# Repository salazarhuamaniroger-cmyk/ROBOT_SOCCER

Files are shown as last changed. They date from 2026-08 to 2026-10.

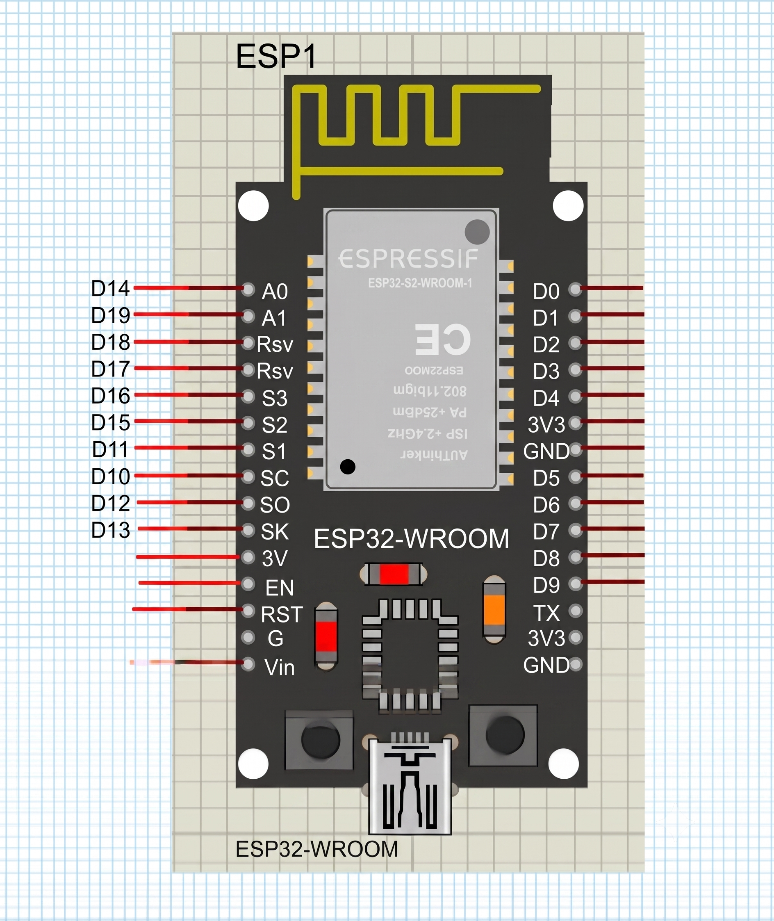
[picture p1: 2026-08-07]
imagenes/equivalencia_de_pines.png

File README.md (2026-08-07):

# 🐂 PITBULL V2.0.0

Sistema de control y desarrollo de un robot SoccerBot basado en **ESP32**, con control mediante interfaz web, comunicación Wi-Fi, simulación electrónica en **Proteus**, programación mediante **Arduino IDE** y modelo 3D para fabricación del chasis.

---

# 📑 Índice

- [Descripción del proyecto](#-descripción-del-proyecto)
- [Estructura del repositorio](#-estructura-del-repositorio)
- [Estructura del proyecto](#-estructura-del-proyecto-1)
  - [Electrónica](#-electrónica)
  - [Código](#-código)
  - [Modelo 3D](#-modelo-3d)
- [Simulación en Proteus](#-simulación-en-proteus)
  - [Esquema electrónico](#-esquema-electrónico)
  - [Instalación de la librería ESP32 en Proteus](#-instalación-de-la-librería-esp32-en-proteus)
  - [Consideraciones sobre la simulación](#-consideraciones-sobre-la-simulación)
  - [Equivalencia de pines](#-equivalencia-de-pines)
  - [Obtención del archivo HEX](#-obtención-del-archivo-hex)
  - [Carga del binario en Proteus](#-carga-del-binario-en-proteus)
- [Código del SoccerBot](#-código-del-soccerbot)
- [Documentación del código](#-documentación-del-código)
  - [Librerías](#1-librerías)
  - [Configuración de red](#2-configuración-de-red)
  - [Asignación de pines](#3-asignación-de-pines)
  - [Watchdog de seguridad](#4-watchdog-de-seguridad)
  - [Interfaz web](#5-interfaz-web)
  - [Control de motores](#6-control-de-motores)
  - [Cinemática Arcade Drive](#7-cinemática-arcade-drive)
  - [Servidor HTTP](#8-servidor-http)
  - [Sistema de secuencia](#9-sistema-de-secuencia)
  - [OTA](#10-actualización-ota)
  - [Loop principal](#11-loop-principal)
- [Flujo general del sistema](#-flujo-general-del-sistema)
- [Modelo 3D](#-modelo-3d-1)
- [Funcionamiento general](#-funcionamiento-general)
- [Consideraciones importantes](#-consideraciones-importantes)
- [Referencias](#-referencias)

---

#  Descripción del proyecto

**PITBULL V2.0.0** es un proyecto de robótica móvil orientado al desarrollo de un **robot SoccerBot**.

El proyecto integra tres áreas principales:

1. **Electrónica**
2. **Programación y control**
3. **Diseño mecánico y fabricación 3D**

El sistema utiliza un **ESP32** como unidad principal de control. El robot puede recibir comandos mediante una interfaz web alojada directamente en el ESP32 utilizando una red Wi-Fi creada por el propio dispositivo.

El proyecto también cuenta con una simulación electrónica desarrollada en **Proteus**, que permite comprobar previamente el funcionamiento lógico del sistema antes de llevarlo al hardware físico.

---

# 📁 Estructura del repositorio

La estructura general del repositorio es la siguiente:

```text
PITBULL-V2.0.0/
│
├── README.md
│       └── Documentación principal del repositorio
│
├── codigo/
│       └── Firmware en C/C++ para Arduino IDE
│
├── electronica/
│       ├── SOCCER 3.0.pdsprj
│       │       └── Esquemático y simulación de Proteus
│       │
│       └── libreria_proteus/
│               ├── ESP32TEP.LIB
│               └── ESP32TEP.IDX
│
├── imagenes/
│       └── Capturas, diagramas de flujo e instrucciones visuales
│
└── modelo_3d/
        └── Archivos CAD (.STL, .STEP) para el chasis```

🏗️**structura del proyecto**

Avanzaremos inicialmente por las partes principales del proyecto.

⚡ Electrónica

El esquema electrónico general del proyecto se encuentra representado en Proteus.

Diagrama general

![DIAGRAMA EN PROTEUS](imagenes/diagrama_general_soccer.png)

El esquema muestra la conexión general de los componentes electrónicos utilizados en el SoccerBot.

📂 Archivos de la simulación

Los archivos principales de la simulación se encuentran en:
/home/tronyx/PITBULL-V2.0.0/electronica/

Dentro de esta carpeta se encuentran principalmente:

1. SOCCER 3.0.pdsprj

Este archivo contiene el proyecto y el esquemático desarrollado en Proteus.

Es el archivo que debe abrirse para acceder a la simulación electrónica.

2. codigo_simulacion_proteus.ino

Este archivo contiene el código utilizado para la simulación.

Puede abrirse mediante Arduino IDE para realizar modificaciones, compilarlo y posteriormente generar el archivo binario necesario para Proteus.

🧩 Librería ESP32 para Proteus

Los componentes utilizados en el esquemático se encuentran principalmente dentro del archivo:

SOCCER 3.0.pdsprj

La excepción corresponde al componente ESP32, debido a que se utiliza una librería externa.

La librería del ESP32 se encuentra dentro del repositorio en:

/home/tronyx/PITBULL-V2.0.0/electronica/libreria_proteus/

Esta carpeta contiene dos archivos:

ESP32TEP.LIB
ESP32TEP.IDX

Estos archivos deben instalarse manualmente en la carpeta correspondiente de Proteus.

🔧 Instalación de la librería ESP32 en Proteus

Para añadir la librería ESP32 a Proteus:

1. Localizar los archivos

Dentro del repositorio se encuentran los siguientes archivos:

/home/tronyx/PITBULL-V2.0.0/electronica/libreria_proteus/

Allí se encuentran:

ESP32TEP.LIB
ESP32TEP.IDX

2. Localizar la carpeta de librerías de Proteus

Busca en tu instalación de Proteus la carpeta donde se encuentran sus librerías.

La ubicación exacta puede variar dependiendo de la versión e instalación de Proteus.

Para localizarla puedes utilizar como referencia la siguiente imagen:

![Librerías de Proteus](/home/tronyx/PITBULL-V2.0.0/imagenes/'añadir libreria_proteus.png')

3. Copiar los archivos

Copia los dos archivos:

ESP32TEP.LIB
ESP32TEP.IDX

dentro de la carpeta:

Libraries

de Proteus.

4. Reiniciar Proteus

Después de copiar los archivos:

Cierra Proteus.
Vuelve a abrir Proteus.
Abre nuevamente el proyecto.
Busca el componente ESP32.

Si todo se realizó correctamente, el componente debería estar disponible.

⚠️ Si el componente ESP32 no aparece

Si el componente no aparece después de instalar la librería:

Verifica que los archivos .LIB y .IDX estén en la carpeta correcta.
Comprueba que Proteus haya sido cerrado antes de copiar los archivos.
Reinicia Proteus.
Comprueba que el archivo del proyecto siga utilizando el componente correcto.

Si el archivo de Proteus fue trasladado de ubicación, revisa también las rutas asociadas al proyecto.

📚 Referencia para instalar librerías

Para obtener información adicional sobre la instalación y configuración de librerías en Proteus:

https://www.theengineeringprojects.com/2018/04/how-to-add-new-library-in-proteus-8.html
⚠️ Consideraciones sobre la simulación

Aunque el componente utilizado en Proteus pueda representar físicamente un ESP32, la simulación utiliza una representación equivalente para permitir el funcionamiento del modelo dentro de Proteus.

Por este motivo, es importante diferenciar entre:

La placa utilizada físicamente.
El componente utilizado en Proteus.
La configuración seleccionada en Arduino IDE para generar el código.

La simulación tiene como objetivo comprobar principalmente:

La lógica del programa.
Las señales de control.
La dirección de los motores.
El comportamiento de las entradas y salidas.
La comunicación entre los diferentes elementos del circuito.

El hardware físico deberá utilizar la versión real de ESP32 correspondiente al diseño final.

🔌 Equivalencia de pines

Debido a que el modelo de ESP32 utilizado en Proteus puede presentar una distribución de pines diferente respecto a la placa física, se debe utilizar una tabla de equivalencias.

![Equivalencia de pines](/home/tronyx/PITBULL-V2.0.0/imagenes/'equivalencia de pines.png')

Esta equivalencia permite adaptar el circuito simulado al hardware real.

Importante: la equivalencia debe comprobarse antes de realizar el montaje físico.

💻 Obtención del archivo HEX

Para ejecutar el firmware dentro de Proteus es necesario proporcionar el archivo binario generado por Arduino IDE.

El procedimiento es el siguiente.

1. Compilar el programa

Abre el código mediante Arduino IDE.

Una vez que el código haya sido verificado y compilado correctamente, abre:

Programa

y posteriormente:

Binarios compilados

2. Localizar el archivo generado

Arduino IDE generará diferentes archivos temporales.

Uno de ellos tendrá una ruta similar a:

**C:\Users\Lenovo\AppData\Local\Temp\arduino_build_438877\codigo_de_prueba_v0003.ino.hex**

El nombre:

codigo_de_prueba_v0003

es solamente un ejemplo.

El nombre real dependerá del nombre que tenga el archivo .ino utilizado en Arduino IDE.

🧪 Carga del binario en Proteus

Una vez obtenido el archivo .hex:

1. Abrir Proteus

Abre:

SOCCER 3.0.pdsprj
2. Seleccionar el ESP32

Haz doble clic sobre el componente ESP32 dentro del esquemático.

Se abrirá la ventana de propiedades del componente.

3. Introducir el archivo HEX

Busca el campo correspondiente al archivo de programa y selecciona el archivo .hex generado por Arduino IDE.

Después pulsa:

OK

La simulación podrá comenzar.

🔄 Si vuelves a modificar el código

El archivo binario es temporal.

Por lo tanto, cada vez que modifiques el código:

Abre el código en Arduino IDE.
Compílalo nuevamente.
Genera el nuevo binario.
Localiza el nuevo archivo .hex.
Vuelve a introducirlo en Proteus.
Ejecuta nuevamente la simulación.

📚 Referencia adicional
Si tienes dificultades para generar o utilizar el binario del ESP32 en Proteus:

https://www.theengineeringprojects.com/2023/07/esp32-library-for-proteus.html

💻 Código del SoccerBot

Una vez validado el flujo lógico, la electrónica y la simulación, se puede trabajar directamente con el firmware y el hardware real del SoccerBot.

El código principal se encuentra en:

/home/tronyx/PITBULL-V2.0.0/codigo/

El firmware debe abrirse mediante Arduino IDE.

🧠 Configuración del robot

El código contiene una constante que define el nombre mostrado en la interfaz:

const char* NOMBRE_ROBOT = "PITBULL V.200";

En la interfaz web este nombre se muestra como:

PITBULL V.200

El nombre puede modificarse directamente desde el código.

📡 Sistema de comunicación

El SoccerBot utiliza el ESP32 como punto de acceso Wi-Fi (Access Point).

Esto significa que el ESP32 crea su propia red inalámbrica.

La configuración utilizada es:

const char* ap_ssid = "SoccerBot-AP";
const char* ap_password = "PITBULL_rt79";

Por lo tanto, el dispositivo que controla el robot debe conectarse a:

SSID:
SoccerBot-AP

con la contraseña:

PITBULL_rt79

La dirección IP habitual del ESP32 en este modo es:

192.168.4.1

Por lo tanto, la interfaz puede abrirse normalmente mediante:

http://192.168.4.1
🌐 Documentación del código

Esta sección explica el funcionamiento interno del firmware.

1. Librerías

El código comienza incluyendo:

#include <WiFi.h>
#include <ArduinoOTA.h>
#include <WebServer.h>
#include <ESPmDNS.h>

Cada librería cumple una función específica.

WiFi.h

Permite configurar y controlar la conexión Wi-Fi del ESP32.

En este proyecto se utiliza para crear el Access Point.

ArduinoOTA.h

Permite realizar actualizaciones del firmware mediante OTA (Over-The-Air).

Esto permite actualizar el programa sin necesidad de conectar físicamente el ESP32 para cada modificación.

WebServer.h

Proporciona el servidor HTTP utilizado para recibir las órdenes provenientes de la interfaz web.

El servidor funciona en el puerto:

80
ESPmDNS.h

Permite utilizar nombres de red mediante mDNS.

El código intenta registrar:

soccerbot.local

como alternativa a utilizar directamente la dirección IP.

2. Configuración de red

El código utiliza:

WiFi.mode(WIFI_AP);

Esto configura al ESP32 como Access Point.

Posteriormente:

WiFi.softAP(ap_ssid, ap_password);

crea la red:

SoccerBot-AP

El ESP32 funciona entonces como el punto central de comunicación.

El flujo es:

Teléfono / Laptop
       │
       │ Wi-Fi
       ▼
   ESP32
       │
       ├── Servidor HTTP
       │
       └── Control de motores

3. Asignación de pines

El código define los pines utilizados por el controlador de motores TB6612FNG.

const int PWMA_PIN = 14;
const int AIN1_PIN = 18;
const int AIN2_PIN = 21;

const int PWMB_PIN = 35;
const int BIN1_PIN = 16;
const int BIN2_PIN = 17;

La estructura lógica es:

Función	Pin
PWMA	GPIO 14
AIN1	GPIO 18
AIN2	GPIO 21
PWMB	GPIO 35
BIN1	GPIO 16
BIN2	GPIO 17

El TB6612FNG utiliza dos canales independientes:

Canal A → Motor izquierdo
Canal B → Motor derecho

4. Watchdog de seguridad

El robot incorpora un mecanismo de seguridad basado en tiempo.

unsigned long lastCommandTime = 0;

const unsigned long COMMAND_TIMEOUT_MS = 300;

El tiempo máximo permitido sin recibir una orden es:

300 ms

Si el ESP32 deja de recibir comandos durante más de ese tiempo, ejecuta:

detenerTodo();

Esto provoca que ambos motores se detengan.

¿Por qué existe el watchdog?

Supongamos que el teléfono pierde la conexión mientras el robot está avanzando.

Sin un mecanismo de seguridad:

Teléfono → "avanzar"
ESP32 → motores funcionando
Teléfono → conexión perdida
ESP32 → podría continuar funcionando

Con el watchdog:

Teléfono → "avanzar"
ESP32 → motores funcionando

Conexión perdida
       ↓
No llegan comandos
       ↓
300 ms
       ↓
detenerTodo()
       ↓
Motores detenidos

Este mecanismo evita que una pérdida de comunicación deje al robot desplazándose indefinidamente.

5. Interfaz web

La interfaz completa está almacenada dentro del firmware mediante:

const char INDEX_HTML[] PROGMEM = R"rawliteral(
...
)rawliteral";

Esto permite almacenar el HTML directamente dentro de la memoria del programa del ESP32.

La interfaz está formada por:

Control mediante botones.
Control mediante joystick lineal.
Limitador de PWM.
Telemetría.
Indicador de red.
Indicador de potencia.
Indicador de giro.
Selector de modo.
Nombre del robot.

🎮 **Modos de control**

La interfaz tiene dos modos principales.

Modo 1: BOTONES

Permite controlar el robot mediante cuatro botones:

        ▲
        │
   ◀         ▶
        │
        ▼

El eje X controla el giro:

X < 0 → izquierda
X > 0 → derecha

El eje Y controla el desplazamiento:

Y > 0 → adelante
Y < 0 → atrás
Modo 2: DUAL PRO

Utiliza dos controles lineales:

Joystick X → Giro
Joystick Y → Potencia

El eje X produce valores entre:

-255 ───── 0 ───── +255

El eje Y también trabaja con valores entre:

-255 ───── 0 ───── +255

6. Control de motores

La función principal encargada del control de los motores es:

void operarMotor(bool esIzquierdo, int velocidad)

Recibe dos parámetros:

esIzquierdo

Indica qué motor se debe controlar.

true

significa motor izquierdo.

false

significa motor derecho.

velocidad

Representa la velocidad y dirección:

-255 → máxima velocidad en una dirección
   0 → detenido
+255 → máxima velocidad en la dirección opuesta

La función determina automáticamente los pines correspondientes:

int in1 = esIzquierdo ? AIN1_PIN : BIN1_PIN;
int in2 = esIzquierdo ? AIN2_PIN : BIN2_PIN;
int pwmPin = esIzquierdo ? PWMA_PIN : PWMB_PIN;
Motor hacia adelante

Cuando:

velocidad > 0

se establece:

digitalWrite(in1, LOW);
digitalWrite(in2, HIGH);

y posteriormente se aplica el PWM:

ledcWrite(pwmPin, velocidad);
Motor hacia atrás

Cuando:

velocidad < 0

se establece:

digitalWrite(in1, HIGH);
digitalWrite(in2, LOW);

La velocidad utilizada por PWM se obtiene mediante:

abs(velocidad)
Motor detenido

Cuando:

velocidad == 0

se establece:

digitalWrite(in1, LOW);
digitalWrite(in2, LOW);
ledcWrite(pwmPin, 0);

7. Cinemática Arcade Drive

El control de movimiento utiliza una estrategia conocida como Arcade Drive aplicada a una plataforma de tracción diferencial.

El navegador envía dos valores:

X = giro
Y = potencia

El ESP32 calcula:

int velIzq = y + x;
int velDer = y - x;

Por lo tanto:

Motor izquierdo = Y + X
Motor derecho    = Y - X
Movimiento hacia adelante

Si:

X = 0
Y = 200

entonces:

Motor izquierdo = 200
Motor derecho   = 200

Ambos motores avanzan a la misma velocidad.

Giro hacia la derecha

Si:

X = 100
Y = 0

entonces:

Motor izquierdo = 100
Motor derecho   = -100

Un motor avanza y el otro retrocede.

Esto produce un giro sobre el propio eje.

Movimiento combinado

Si:

X = 50
Y = 200

entonces:

Motor izquierdo = 250
Motor derecho   = 150

El robot avanza mientras gira.

Limitación de velocidad

Después de calcular las velocidades se aplica:

velIzq = constrain(velIzq, -255, 255);
velDer = constrain(velDer, -255, 255);

Esto garantiza que ningún valor supere el rango permitido:

-255 ≤ velocidad ≤ 255

8. Servidor HTTP

El ESP32 crea:

WebServer server(80);

Esto significa que el servidor HTTP utiliza el puerto:

80
Ruta principal /

La ruta:

/

devuelve la interfaz web.

El código correspondiente es:

server.on("/", []() {
    server.send(200, "text/html", INDEX_HTML);
});

Cuando el usuario accede a:

http://192.168.4.1/

el ESP32 devuelve el HTML almacenado en:

INDEX_HTML

9. Ruta /move

La ruta más importante del sistema es:

/move

Esta ruta recibe los valores:

x
y
seq

Un ejemplo sería:

/move?x=100&y=200&seq=25

El ESP32 obtiene:

int x = server.arg("x").toInt();
int y = server.arg("y").toInt();

y posteriormente calcula las velocidades de los motores.

Formato de la comunicación

El navegador genera una solicitud HTTP:

Teléfono
   │
   │ GET /move?x=100&y=200&seq=25
   ▼
 ESP32
   │
   ├── x = 100
   ├── y = 200
   └── seq = 25
        │
        ▼
 Cinemática
        │
        ▼
 TB6612FNG
        │
        ▼
 Motores
10. Sistema de secuencia

El código utiliza:

uint32_t lastSeq = 0;

La interfaz web mantiene un contador:

let seqCounter = 0;

Cada comando genera un número de secuencia nuevo:

const seq = ++seqCounter;

Esto permite identificar comandos antiguos.

El ESP32 compara:

if (seq < lastSeq)

Si el paquete recibido tiene una secuencia inferior a la última procesada, se considera antiguo:

server.send(200, "text/plain", "STALE");

De esta manera se evita procesar determinados comandos que hayan llegado fuera de orden.

11. Heartbeat del joystick

El modo DUAL PRO incorpora un mecanismo denominado heartbeat.

Cuando el usuario mantiene el joystick en una posición, la interfaz envía periódicamente el comando actual.

El intervalo utilizado es:

100 ms

Esto es importante debido al watchdog del ESP32.

El watchdog requiere recibir comandos dentro de:

300 ms

El heartbeat envía comandos cada:

100 ms

por lo que el ESP32 continúa considerando válida la orden mientras el usuario mantiene el joystick.

12. Limitador de PWM

La interfaz incorpora un control denominado:

LÍMITE PWM

El rango utilizado es:

50 → 255

El valor inicial es:

255

El objetivo es limitar la velocidad máxima solicitada desde la interfaz.

El valor se almacena en:

let maxLimit = 255;
13. Failsafe del navegador

La interfaz también implementa una protección adicional.

Se utiliza:

document.addEventListener('visibilitychange', ...)

Cuando la página pasa a segundo plano:

if (document.hidden)

se ejecuta:

stopAccX();
stopAccY();

Esto permite detener el control cuando, por ejemplo:

Se cambia de aplicación.
Se bloquea la pantalla.
Se abandona la página.

El objetivo es evitar que el robot continúe recibiendo comandos desde una interfaz que ya no está siendo controlada activamente.

14. Actualización OTA

El código incluye:

#include <ArduinoOTA.h>

y durante el inicio ejecuta:

ArduinoOTA.begin();

Posteriormente, en el loop():

ArduinoOTA.handle();

Esto permite gestionar las actualizaciones OTA.

El objetivo es poder actualizar el firmware utilizando la conexión de red disponible, evitando tener que conectar físicamente el programador cada vez que se realice una modificación del programa.

15. mDNS

El código intenta registrar el nombre:

soccerbot.local

mediante:

MDNS.begin("soccerbot")

Si el registro funciona correctamente, se puede intentar acceder mediante:

http://soccerbot.local

Sin embargo, dependiendo del dispositivo utilizado para controlar el robot, la resolución mDNS puede no funcionar correctamente.

Por esta razón, la dirección IP directa:

http://192.168.4.1

continúa siendo la referencia principal.

🔄 Flujo general del sistema

El funcionamiento completo puede representarse de la siguiente manera:

                  ┌─────────────────────┐
                  │       USUARIO       │
                  │ Teléfono / Laptop   │
                  └──────────┬──────────┘
                             │
                             │ Wi-Fi
                             ▼
                  ┌─────────────────────┐
                  │        ESP32        │
                  │   Access Point      │
                  │   192.168.4.1       │
                  └──────────┬──────────┘
                             │
                  ┌──────────┴──────────┐
                  │                     │
                  ▼                     ▼
          ┌───────────────┐     ┌───────────────┐
          │ Servidor HTTP │     │    Watchdog   │
          │     /move     │     │    300 ms     │
          └───────┬───────┘     └───────────────┘
                  │
                  ▼
          ┌───────────────┐
          │    Vector     │
          │    X / Y      │
          └───────┬───────┘
                  │
                  ▼
          ┌───────────────┐
          │ Arcade Drive  │
          │               │
          │ Izq = Y + X   │
          │ Der = Y - X   │
          └───────┬───────┘
                  │
                  ▼
          ┌───────────────┐
          │   TB6612FNG   │
          └───────┬───────┘
                  │
             ┌────┴────┐
             ▼         ▼
        Motor Izq.  Motor Der.

🧱 Modelo 3D

El modelo mecánico del robot se encuentra en:

/home/tronyx/PITBULL-V2.0.0/modelo_3d/

Dentro de esta carpeta se almacenan los archivos relacionados con el diseño CAD del robot.

Los formatos principales son:

.STL
.STEP
Formato STL

El formato .STL puede utilizarse principalmente para:

Impresión 3D.
Preparación del modelo en un slicer.
Fabricación de piezas.
Formato STEP

El formato .STEP permite trabajar con el modelo CAD de forma más editable y facilita modificaciones posteriores del diseño.

🖨️ Fabricación 3D

El modelo puede utilizarse para generar las piezas necesarias para fabricar el chasis del SoccerBot.

El flujo general es:

Modelo CAD
    │
    ▼
Archivo STEP / STL
    │
    ▼
Slicer
    │
    ▼
Impresora 3D
    │
    ▼
Pieza física

El modelo también puede modificarse para cambiar las características mecánicas del robot.

🧪 Funcionamiento general

El flujo completo del proyecto es:

                 DESARROLLO
                     │
        ┌────────────┼────────────┐
        │            │            │
        ▼            ▼            ▼
   Electrónica     Código      Modelo 3D
        │            │            │
        ▼            ▼            ▼
    Proteus      Arduino IDE    Fusion
        │            │            │
        ▼            ▼            ▼
   Simulación     Firmware      Chasis
        │            │            │
        └────────────┼────────────┘
                     ▼
                HARDWARE REAL
                     │
                     ▼
                  ESP32
                     │
                     ▼
                 TB6612FNG
                     │
             ┌───────┴───────┐
             ▼               ▼
        Motor izquierdo   Motor derecho

⚠️ C**onsideraciones importantes**

1. Simulación ≠ hardware físico

La simulación de Proteus es una representación del sistema.

Antes de montar el hardware real se deben verificar:

Alimentación.
Distribución de pines.
Corriente de los motores.
Conexiones del TB6612FNG.
GND común.
Alimentación del ESP32.
Polaridad de los motores.

2. Dirección de los motores

La dirección física de un motor depende de cómo estén conectados sus terminales.

Por ello, si el robot se mueve en dirección contraria a la esperada, primero debe comprobarse:

Motor
  │
  ├── Terminal A
  └── Terminal B

y posteriormente la lógica:

AIN1
AIN2

o:

BIN1
BIN2

3. Valores PWM

El sistema utiliza un rango:

-255 → 255

donde:

0   = detenido
255 = máxima potencia en un sentido
-255 = máxima potencia en el sentido contrario

4. Watchdog

El watchdog está configurado en:

const unsigned long COMMAND_TIMEOUT_MS = 300;

Esto significa que la comunicación con el robot debe mantenerse continuamente durante el movimiento.

5. Nombre del archivo HEX

El archivo .hex generado por Arduino IDE puede cambiar de nombre dependiendo del nombre del proyecto y de la compilación.

Por ejemplo:

codigo_de_prueba_v0003.ino.hex

no debe interpretarse como un nombre fijo.

6. Archivo binario para Proteus

Cada modificación del firmware requiere generar nuevamente el archivo binario antes de ejecutar la simulación con la nueva versión.

7. GPIO utilizado para PWMB

El firmware actual define:

const int PWMB_PIN = 35;

Este pin debe verificarse específicamente contra la placa ESP32 utilizada físicamente, ya que la disponibilidad de funciones de salida/PWM depende del modelo concreto de ESP32.

No se debe asumir que todos los GPIO tienen las mismas capacidades en todas las variantes de ESP32.

📂 **Rutas principales del proyecto**
Código
/home/tronyx/PITBULL-V2.0.0/codigo/
Electrónica
/home/tronyx/PITBULL-V2.0.0/electronica/
Librería Proteus
/home/tronyx/PITBULL-V2.0.0/electronica/libreria_proteus/
Imágenes
/home/tronyx/PITBULL-V2.0.0/imagenes/
Modelo 3D
/home/tronyx/PITBULL-V2.0.0/modelo_3d/
🔗 Referencias
Instalación de librerías en Proteus
https://www.theengineeringprojects.com/2018/04/how-to-add-new-library-in-proteus-8.html
Librería ESP32 para Proteus
https://www.theengineeringprojects.com/2023/07/esp32-library-for-proteus.html

📝 **Estado del proyecto**

El proyecto se encuentra organizado en tres componentes principales:

PITBULL V2.0.0
│
├── ⚡ Electrónica
│   └── Proteus + ESP32 + TB6612FNG
│
├── 💻 Software
│   └── Arduino IDE + ESP32 + WebServer
│
└── 🧱 Mecánica
    └── Modelo 3D + fabricación

El objetivo es mantener separadas las diferentes áreas del proyecto para facilitar su desarrollo, simulación, depuración y fabricación.

👨‍💻 Desarrollo

El firmware está desarrollado en:

C/C++

utilizando:

Arduino IDE

y está destinado al control de un robot móvil basado en ESP32.

El sistema integra:

Wi-Fi.
Access Point.
Servidor HTTP.
Interfaz web.
Control PWM.
TB6612FNG.
Arcade Drive.
Watchdog de seguridad.
Heartbeat.
Control mediante botones.
Joystick dual.
mDNS.
OTA.
Simulación mediante Proteus.
Diseño mecánico 3D.

### Una observación importante sobre tu código

He documentado **exactamente la arquitectura que tienes actualmente**, pero encontré un punto que conviene revisar antes de dar por cerrado el README: tienes definido:

```cpp
const int PWMB_PIN = 35;

El GPIO 35 puede ser problemático dependiendo de la variante concreta de ESP32, porque en varias familias de ESP32 ese GPIO es de entrada solamente. Como tu código utiliza:

ledcAttach(PWMB_PIN, 1000, 8);

para generar PWM, hay que verificar qué ESP32 exacto estás utilizando físicamente antes de afirmar que GPIO35 es válido como salida PWM.

No lo he cambiado en el README porque me pediste mejorar y estructurar el contenido, no modificar tu firmware, pero sí lo he dejado señalado como punto técnico que debe verificarse.

Además, mantuve las rutas originales, incluyendo:

/home/tronyx/PITBULL-V2.0.0/electronica/
/home/tronyx/PITBULL-V2.0.0/electronica/libreria_proteus/
/home/tronyx/PITBULL-V2.0.0/imagenes/
/home/tronyx/PITBULL-V2.0.0/modelo_3d/

y los dos enlaces de The Engineering Projects.

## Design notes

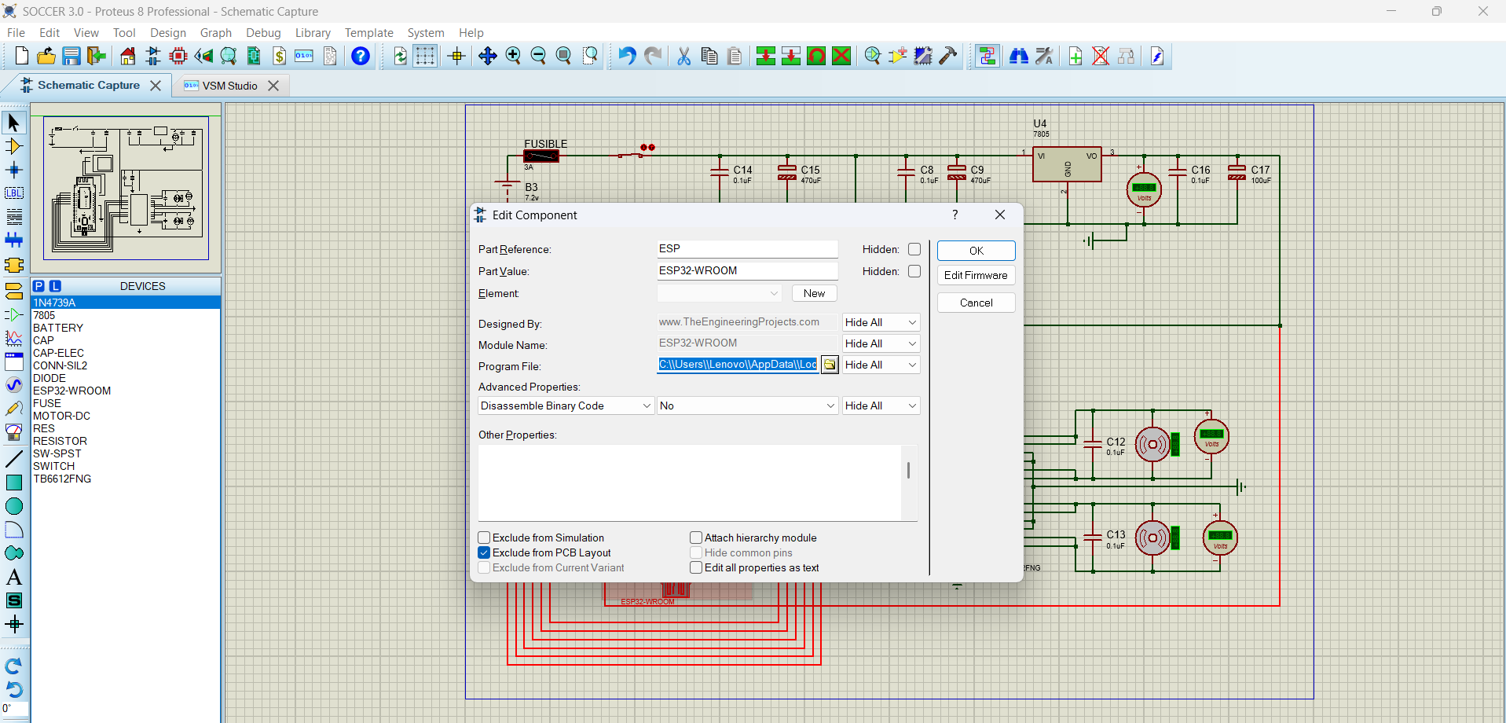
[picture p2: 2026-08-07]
imagenes/ruta_binario_sp32.png

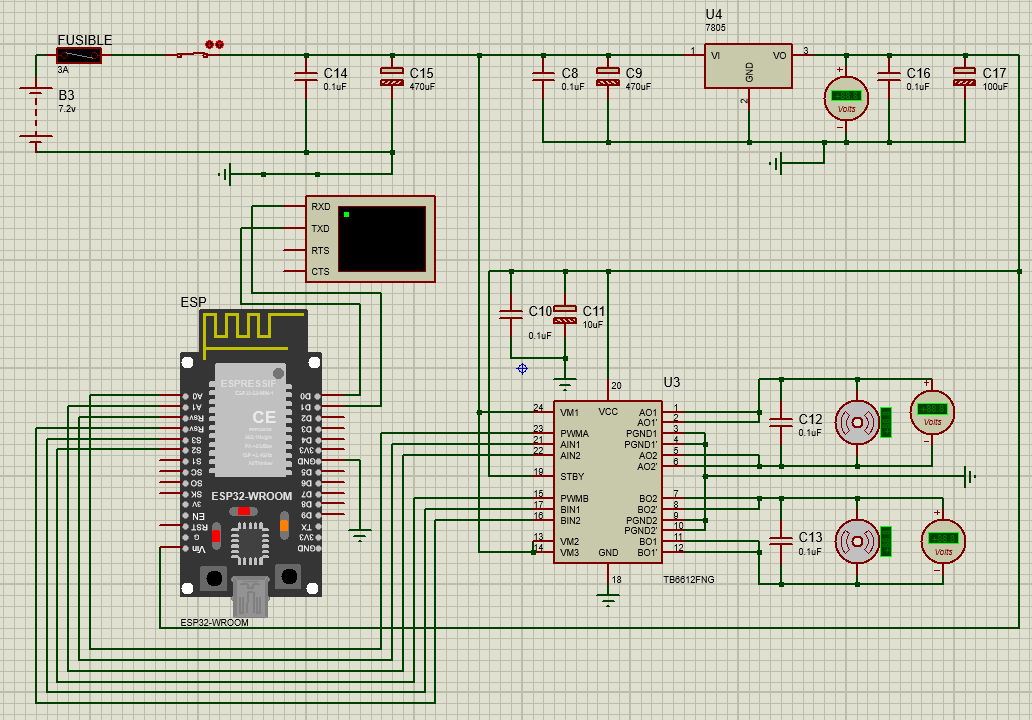
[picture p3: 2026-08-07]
imagenes/diagrama_general_soccer.png

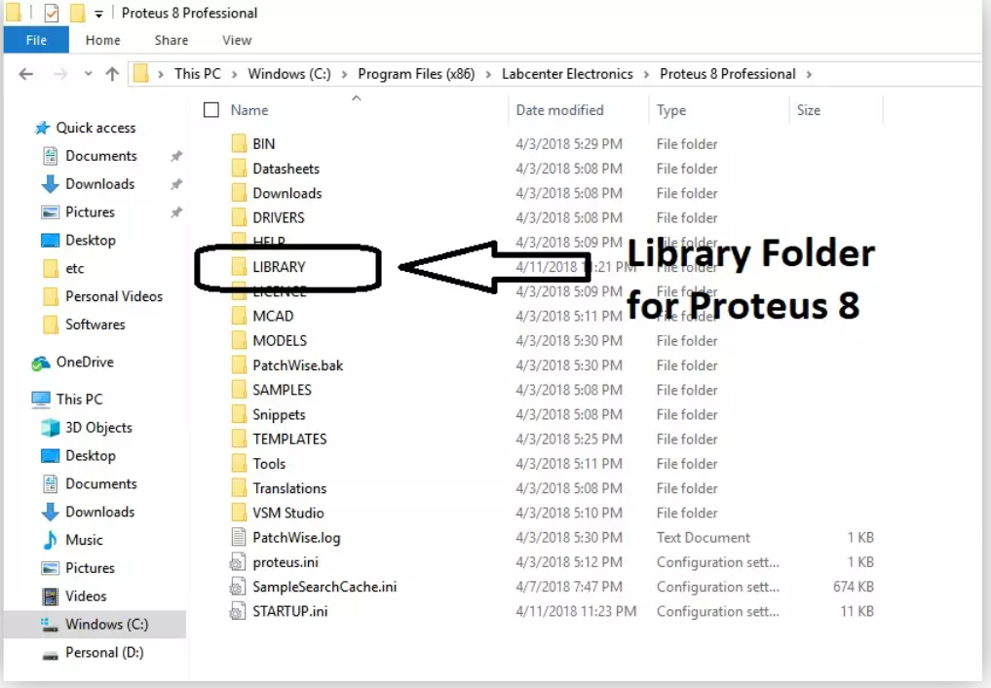
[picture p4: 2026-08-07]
imagenes/añadir_libreria_proteus.png

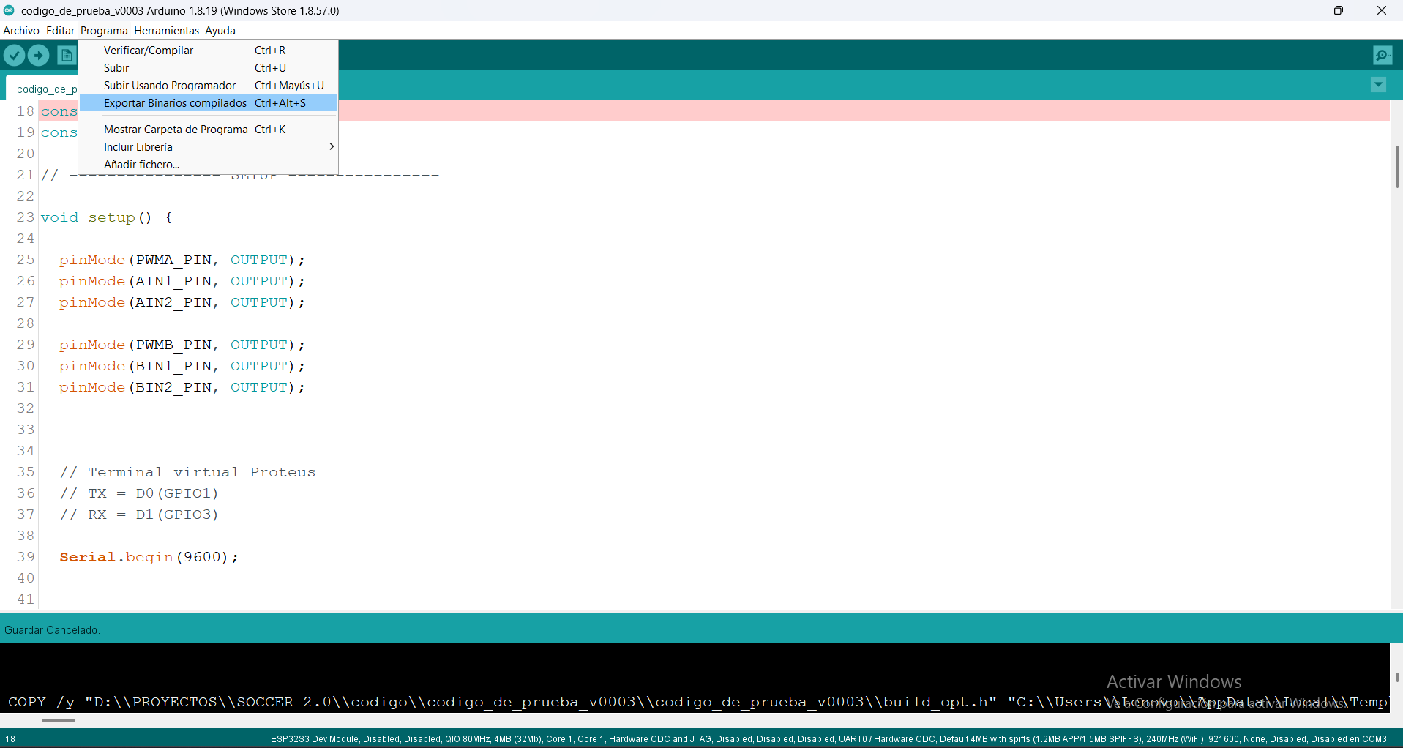
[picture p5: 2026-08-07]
imagenes/binario_para_proteus.png

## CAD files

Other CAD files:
modelo_3d/SOCCER_CORREGIDO_3D.f3d

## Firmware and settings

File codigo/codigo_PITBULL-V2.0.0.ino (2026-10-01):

#include <WiFi.h>
#include <ArduinoOTA.h>
#include <WebServer.h>
#include <ESPmDNS.h>

// ================= CONFIGURACIÓN DE RED (MODO ACCESS POINT) =================
const char* ap_ssid = "SoccerBot-AP";
const char* ap_password = "password"; // Minimo 8 caracteres, requerido por el estandar WiFi-SP32-S3
WebServer server(80);

// ================= ASIGNACIÓN DE PINES (TB6612FNG) =================
const int PWMA_PIN = 14;
const int AIN1_PIN = 18;
const int AIN2_PIN = 21; // Motor A (Asumiremos que es el Izquierdo)

const int PWMB_PIN = 7;// modificado del 35 al 7 porque 35 se quemo
const int BIN1_PIN = 16;
const int BIN2_PIN = 17; // Motor B (Asumiremos que es el Derecho)

// ================= WATCHDOG DE SEGURIDAD =================
unsigned long lastCommandTime = 0;
const unsigned long COMMAND_TIMEOUT_MS = 300; // Si no llega orden en 300ms, freno de emergencia
uint32_t lastSeq = 0; // Ultimo numero de secuencia procesado (anti-desorden de paquetes)

// ================= INTERFAZ WEB TACTICAL V4 (PROGMEM) =================
const char INDEX_HTML[] PROGMEM = R"rawliteral(
<!DOCTYPE html>
<html lang="es">
<head>
    <meta charset="UTF-8">
    <meta name="viewport" content="width=device-width, initial-scale=1.0, maximum-scale=1.0, user-scalable=no, orientation=landscape, viewport-fit=cover">
    <title>SOCCERBOT PRO</title>
    <style>
        @import url('https://fonts.googleapis.com/css2?family=Share+Tech+Mono&display=swap');
        :root {
            --bg-base: #050608; --panel-bg: #10121a; --border-dark: #1f2433;
            --text-muted: #64748b; --neon-blue: #00e5ff; --neon-orange: #ff4d00;
            --neon-green: #00ff66; --neon-red: #ff0033;
        }
        * { box-sizing: border-box; margin: 0; padding: 0; user-select: none; -webkit-user-select: none; touch-action: none; }
        html, body { height: 100%; width: 100%; }
        body {
            font-family: 'Segoe UI', sans-serif; background-color: var(--bg-base); color: #fff;
            height: 100vh; width: 100vw;
            height: 100dvh; width: 100dvw;
            overflow: hidden; display: grid;
            grid-template-columns: 1fr 240px 1fr;
            grid-template-rows: minmax(50px, 65px) 1fr;
            gap: 10px;
            padding-top: 10px;
            padding-bottom: 10px;
            padding-left: calc(10px + env(safe-area-inset-left));
            padding-right: calc(10px + env(safe-area-inset-right));
        }
        #orientation-warning {
            display: none; position: fixed; top: 0; left: 0; width: 100%; height: 100%; background: var(--neon-red);
            color: white; z-index: 9999; align-items: center; justify-content: center; flex-direction: column; font-size: 24px; font-weight: bold; text-align: center;
        }
        @media screen and (orientation: portrait) { #orientation-warning { display: flex; } body { display: none; } }

        .top-bar {
            grid-column: 1 / 4; background: var(--panel-bg); border: 2px solid var(--border-dark); border-radius: 12px;
            display: flex; align-items: center; justify-content: flex-start; padding: 0 20px; gap: 20px;
            min-height: 0;
        }
        .top-bar.hidden { visibility: hidden; }
        .slider-label { font-family: 'Share Tech Mono', monospace; font-size: 16px; color: var(--neon-orange); font-weight: bold; white-space: nowrap; width: 150px; }
        .slider-wrapper { flex: 1; display: flex; flex-direction: column; position: relative; padding-top: 5px; }
        input[type=range] { width: 100%; -webkit-appearance: none; background: #1e293b; height: 8px; border-radius: 4px; outline: none; z-index: 2; position: relative; }
        input[type=range]::-webkit-slider-thumb { -webkit-appearance: none; width: 28px; height: 28px; border-radius: 50%; background: var(--neon-orange); cursor: pointer; border: 3px solid #fff; box-shadow: 0 0 10px rgba(255, 77, 0, 0.5); }
        .ruler-ticks { display: flex; justify-content: space-between; padding: 0 10px; margin-top: 2px; pointer-events: none; }
        .tick { display: flex; flex-direction: column; align-items: center; font-family: 'Share Tech Mono', monospace; font-size: 9px; color: var(--text-muted); }
        .tick::before { content: ''; width: 2px; height: 6px; background: var(--text-muted); margin-bottom: 2px; }

        .control-zone { background: var(--panel-bg); border: 2px solid var(--border-dark); border-radius: 16px; display: flex; align-items: center; justify-content: center; position: relative; min-height: 0; min-width: 0; overflow: hidden; }
        .center-dash { display: flex; flex-direction: column; gap: 10px; justify-content: flex-start; min-height: 0; overflow: hidden; }
        .mode-selector { display: flex; border: 2px solid var(--border-dark); border-radius: 10px; overflow: hidden; background: var(--panel-bg); }
        .mode-btn { flex: 1; background: transparent; color: var(--text-muted); border: none; padding: 12px 5px; font-size: 12px; font-weight: bold; cursor: pointer; }
        .mode-btn.active { background: #1a1e2b; color: #fff; border-bottom: 2px solid var(--neon-blue); }
        .telemetry-grid { display: grid; grid-template-columns: 1fr 1fr; gap: 8px; }
        .t-card { background: var(--panel-bg); border: 1px solid var(--border-dark); border-radius: 10px; display: flex; flex-direction: column; align-items: center; justify-content: center; padding: 12px 5px; }
        .t-label { font-size: 10px; color: var(--text-muted); }
        .t-value { font-family: 'Share Tech Mono', monospace; font-size: 18px; margin-top: 4px; color: #e2e8f0; }
        .c-green { color: var(--neon-green); text-shadow: 0 0 8px rgba(0,255,102,0.5); }
        .c-red { color: var(--neon-red); text-shadow: 0 0 8px rgba(255,0,51,0.5); }
        .robot-name-display { margin-top: auto; margin-bottom: 10px; text-align: center; font-family: 'Share Tech Mono', monospace; font-size: 26px; font-weight: bold; color: var(--neon-red); letter-spacing: 2px; text-shadow: 0 0 12px rgba(255, 0, 51, 0.4); }

        .view { position: absolute; width: 100%; height: 100%; display: none; align-items: center; justify-content: center; }
        .view.active { display: flex; }
        .btn-group { display: flex; gap: 20px; justify-content: center; align-items: center; width: 100%; height: 100%; }
        .btn-group.vertical { flex-direction: column; }
        .btn-pad { width: clamp(60px, 16vh, 100px); height: clamp(60px, 16vh, 100px); background: linear-gradient(145deg, #1f2433, #151822); border: 2px solid #2a3143; border-radius: 20px; display: flex; align-items: center; justify-content: center; font-size: clamp(24px, 6vh, 35px); color: #64748b; box-shadow: 0 8px 15px rgba(0,0,0,0.4); }
        .btn-pad:active { transform: scale(0.92); }
        .btn-pad.x-axis:active { border-color: var(--neon-blue); color: var(--neon-blue); box-shadow: inset 0 0 15px rgba(0,229,255,0.3); }
        .btn-pad.y-axis:active { border-color: var(--neon-orange); color: var(--neon-orange); box-shadow: inset 0 0 15px rgba(255,77,0,0.3); }

        .track { background: #0d0e14; border: 2px solid #1a1e2b; border-radius: 50px; position: relative; display: flex; align-items: center; justify-content: center; }
        .track.horizontal { width: 90%; height: clamp(60px, 16vh, 100px); }
        .track.vertical { height: 90%; width: clamp(60px, 16vh, 100px); }
        .track-center-line { position: absolute; background: var(--text-muted); opacity: 0.3; }
        .track.horizontal .track-center-line { width: 4px; height: 100%; }
        .track.vertical .track-center-line { height: 4px; width: 100%; }
        .graduations { position: absolute; font-family: 'Share Tech Mono', monospace; font-size: 10px; color: var(--text-muted); pointer-events: none; display: flex; justify-content: space-between; }
        .track.horizontal .graduations { width: 85%; top: 5px; flex-direction: row; }
        .track.horizontal .graduations.bottom { top: auto; bottom: 5px; }
        .track.vertical .graduations { height: 85%; right: 5px; flex-direction: column; align-items: flex-end; }
        .track.vertical .graduations.left { right: auto; left: 5px; align-items: flex-start; }
        .handle { width: clamp(50px, 13vh, 80px); height: clamp(50px, 13vh, 80px); border-radius: 50%; position: absolute; cursor: pointer; box-shadow: 0 4px 10px rgba(0,0,0,0.8); z-index: 10; }
        .handle.x-handle { background: radial-gradient(circle, #00b4d8, #0077b6); border: 3px solid var(--neon-blue); }
        .handle.y-handle { background: radial-gradient(circle, #ff6d00, #dd2c00); border: 3px solid var(--neon-orange); }
    </style>
</head>
<body>
    <div id="orientation-warning">GIRA EL TELÉFONO</div>
    <div class="top-bar" id="speed-limiter">
        <div class="slider-label">LÍMITE PWM: <span id="lbl-limit">255</span></div>
        <div class="slider-wrapper">
            <input type="range" min="50" max="255" value="255" step="5" oninput="updateLimit(this.value)">
            <div class="ruler-ticks"><div class="tick">50</div><div class="tick">100</div><div class="tick">150</div><div class="tick">200</div><div class="tick">255</div></div>
        </div>
    </div>

    <div class="control-zone">
        <div class="view mode-1 active">
            <div class="btn-group">
                <div class="btn-pad x-axis" onpointerdown="startAccX(-1)" onpointerup="stopAccX()" onpointerleave="stopAccX()" onpointercancel="stopAccX()">◀</div>
                <div class="btn-pad x-axis" onpointerdown="startAccX(1)" onpointerup="stopAccX()" onpointerleave="stopAccX()" onpointercancel="stopAccX()">▶</div>
            </div>
        </div>
        <div class="view mode-2">
            <div class="track horizontal" id="track-x">
                <div class="graduations"><span>-255</span><span>-128</span><span></span><span>128</span><span>255</span></div>
                <div class="graduations bottom"><span></span><span></span><span>0</span><span></span><span></span></div>
                <div class="track-center-line"></div>
                <div class="handle x-handle" id="handle-x"></div>
            </div>
        </div>
    </div>

    <div class="center-dash">
        <div class="mode-selector"><button class="mode-btn active" onclick="setMode(1)">BOTONES</button><button class="mode-btn" onclick="setMode(2)">DUAL PRO</button></div>
        <div class="telemetry-grid">
            <div class="t-card"><span class="t-label">NET</span><span class="t-value" id="val-net">--</span></div>
            <div class="t-card"><span class="t-label">BATTERY</span><span class="t-value">12.4V</span></div>
            <div class="t-card"><span class="t-label">GIRO (X)</span><span class="t-value" id="val-x">0</span></div>
            <div class="t-card"><span class="t-label">POWER (Y)</span><span class="t-value" id="val-y">0</span></div>
        </div>
        <div class="robot-name-display" id="ui-robot-name"></div>
    </div>

    <div class="control-zone">
        <div class="view mode-1 active">
            <div class="btn-group vertical">
                <div class="btn-pad y-axis" onpointerdown="startAccY(1)" onpointerup="stopAccY()" onpointerleave="stopAccY()" onpointercancel="stopAccY()">▲</div>
                <div class="btn-pad y-axis" onpointerdown="startAccY(-1)" onpointerup="stopAccY()" onpointerleave="stopAccY()" onpointercancel="stopAccY()">▼</div>
            </div>
        </div>
        <div class="view mode-2">
            <div class="track vertical" id="track-y">
                <div class="graduations"><span>255</span><span>128</span><span></span><span>-128</span><span>-255</span></div>
                <div class="graduations left"><span></span><span></span><span>0</span><span></span><span></span></div>
                <div class="track-center-line"></div>
                <div class="handle y-handle" id="handle-y"></div>
            </div>
        </div>
    </div>

    <script>
        const NOMBRE_ROBOT = "PITBULL V.200";
        document.getElementById('ui-robot-name').innerText = NOMBRE_ROBOT;

        let maxLimit = 255;
        let currentX = 0, currentY = 0;
        let lastSendTime = 0;

        // Numero de secuencia incremental: permite al ESP32 descartar paquetes
        // que lleguen fuera de orden por congestion de red.
        let seqCounter = 0;

        // Indicador simple de estado de red (ultimo fetch exitoso vs fallido)
        function setNetStatus(ok) {
            const el = document.getElementById('val-net');
            el.innerText = ok ? 'ONLINE' : 'ERROR';
            el.className = 't-value ' + (ok ? 'c-green' : 'c-red');
        }

        // Función unificada que envía el vector (X,Y) al ESP32
        function sendVector(force = false) {
            const now = Date.now();
            if (!force && now - lastSendTime < 60) return; // Evita saturar la red (máx 16 envíos/segundo)
            lastSendTime = now;

            document.getElementById('val-x').innerText = Math.round(currentX);
            document.getElementById('val-y').innerText = Math.round(currentY);

            const seq = ++seqCounter;
            fetch(`/move?x=${Math.round(currentX)}&y=${Math.round(currentY)}&seq=${seq}`)
                .then(() => setNetStatus(true))
                .catch(() => setNetStatus(false));
        }

        function setMode(mode) {
            document.querySelectorAll('.mode-btn').forEach((btn, idx) => btn.classList.toggle('active', idx === mode - 1));
            document.querySelectorAll('.mode-1').forEach(el => el.classList.toggle('active', mode === 1));
            document.querySelectorAll('.mode-2').forEach(el => el.classList.toggle('active', mode === 2));
            const topBar = document.getElementById('speed-limiter');
            if(mode === 2) topBar.classList.add('hidden'); else topBar.classList.remove('hidden');
            stopAccX(); stopAccY();
        }

        function updateLimit(val) {
            maxLimit = parseInt(val);
            document.getElementById('lbl-limit').innerText = maxLimit;
        }

        let timerX, timerY; const ACC_STEP = 15; const ACC_DELAY = 30;

        function startAccX(dir) {
            clearInterval(timerX); currentX = 0;
            timerX = setInterval(() => {
                currentX += ACC_STEP * dir;
                if (dir > 0 && currentX > maxLimit) currentX = maxLimit;
                if (dir < 0 && currentX < -maxLimit) currentX = -maxLimit;
                sendVector();
            }, ACC_DELAY);
        }
        function stopAccX() { clearInterval(timerX); currentX = 0; sendVector(true); }

        function startAccY(dir) {
            clearInterval(timerY); currentY = 0;
            timerY = setInterval(() => {
                currentY += ACC_STEP * dir;
                if (dir > 0 && currentY > maxLimit) currentY = maxLimit;
                if (dir < 0 && currentY < -maxLimit) currentY = -maxLimit;
                sendVector();
            }, ACC_DELAY);
        }
        function stopAccY() { clearInterval(timerY); currentY = 0; sendVector(true); }

        // Failsafe extra en el cliente: si la pestaña pasa a segundo plano
        // (se bloquea la pantalla, se cambia de app, etc.) frenamos todo.
        document.addEventListener('visibilitychange', () => {
            if (document.hidden) {
                stopAccX();
                stopAccY();
            }
        });

        function makeLinearJoystick(trackId, handleId, axis) {
            const track = document.getElementById(trackId);
            const handle = document.getElementById(handleId);
            let active = false;
            let heartbeatTimer = null; // Mantiene vivo el watchdog mientras el handle está sostenido quieto

            const startTrack = (e) => {
                active = true;
                handle.style.transition = 'none';
                moveHandle(e);

                // HEARTBEAT: aunque no haya movimiento, reenvía el vector actual
                // cada 100ms mientras el dedo siga sobre el handle. Esto evita que
                // el watchdog del ESP32 (300ms) frene los motores al mantener
                // el joystick fijo en una posición sin desplazarlo.
                clearInterval(heartbeatTimer);
                heartbeatTimer = setInterval(() => {
                    if (active) sendVector(true);
                }, 100);
            };
            const moveHandle = (e) => {
                if (!active) return;
                e.preventDefault();
                const rect = track.getBoundingClientRect();
                const pointer = e.touches ? e.touches[0] : e;

                let rawPos = 0, maxTravel = 0, mathVal = 0;
                if (axis === 'X') {
                    maxTravel = (rect.width / 2) - (handle.offsetWidth / 2) - 5;
                    rawPos = pointer.clientX - (rect.left + rect.width / 2);
                } else {
                    maxTravel = (rect.height / 2) - (handle.offsetHeight / 2) - 5;
                    rawPos = pointer.clientY - (rect.top + rect.height / 2);
                }

                let boundedPos = Math.max(-maxTravel, Math.min(rawPos, maxTravel));
                mathVal = Math.round((boundedPos / maxTravel) * 255);

                if (axis === 'X') {
                    handle.style.transform = `translateX(${boundedPos}px)`;
                    currentX = mathVal;
                } else {
                    handle.style.transform = `translateY(${boundedPos}px)`;
                    currentY = -mathVal;
                }
                sendVector();
            };
            const endTrack = () => {
                if (!active) return;
                active = false;
                clearInterval(heartbeatTimer);
                handle.style.transition = 'transform 0.15s cubic-bezier(0.175, 0.885, 0.32, 1.275)';
                handle.style.transform = 'translate(0px, 0px)';
                if (axis === 'X') currentX = 0; else currentY = 0;
                sendVector(true);
            };

            track.addEventListener('mousedown', startTrack); window.addEventListener('mousemove', moveHandle); window.addEventListener('mouseup', endTrack);
            track.addEventListener('touchstart', startTrack, { passive: false }); window.addEventListener('touchmove', moveHandle, { passive: false }); window.addEventListener('touchend', endTrack);
            track.addEventListener('pointercancel', endTrack);
        }
        makeLinearJoystick('track-x', 'handle-x', 'X');
        makeLinearJoystick('track-y', 'handle-y', 'Y');
    </script>
</body>
</html>
)rawliteral";



// ================= FUNCIÓN MAESTRA DE CONTROL DE MOTORES =================
// Traduce la velocidad requerida (-255 a 255) en los pines lógicos del TB6612FNG
void operarMotor(bool esIzquierdo, int velocidad) {
    int in1 = esIzquierdo ? AIN1_PIN : BIN1_PIN;
    int in2 = esIzquierdo ? AIN2_PIN : BIN2_PIN;
    int pwmPin = esIzquierdo ? PWMA_PIN : PWMB_PIN;

    if (velocidad > 0) {
        // Adelante (CORREGIDO: Se invirtieron los estados lógicos)
        digitalWrite(in1, LOW);
        digitalWrite(in2, HIGH);
        ledcWrite(pwmPin, velocidad);
    } else if (velocidad < 0) {
        // Atrás (CORREGIDO: Se invirtieron los estados lógicos)
        digitalWrite(in1, HIGH);
        digitalWrite(in2, LOW);
        ledcWrite(pwmPin, abs(velocidad));
    } else {
        // Detener (Freno pasivo, se mantiene igual)
        digitalWrite(in1, LOW);
        digitalWrite(in2, LOW);
        ledcWrite(pwmPin, 0);
    }
}

// ================= FRENO DE EMERGENCIA (usado por el watchdog) =================
void detenerTodo() {
    operarMotor(true, 0);
    operarMotor(false, 0);
}
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
void loop() {
    ArduinoOTA.handle();
    server.handleClient();

    // ===== WATCHDOG DE SEGURIDAD =====
    if (millis() - lastCommandTime > COMMAND_TIMEOUT_MS) {
        detenerTodo();
    }
}

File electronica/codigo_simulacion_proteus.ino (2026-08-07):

// --- Configuración ESP32 + TB6612FNG ---

// Motor A (Motor izquierdo)
const int PWMA_PIN = 14;
const int AIN1_PIN = 18;
const int AIN2_PIN = 19;

// Motor B (Motor derecho)
const int PWMB_PIN = 15;
const int BIN1_PIN = 16;
const int BIN2_PIN = 17;


// Velocidad inicial PWM (0 - 255)
int VELOCIDAD = 150;

// pines del terminal virtual
const int TX= 0;
const int Rx= 1;

// ---------------- SETUP ----------------

void setup() {

  pinMode(PWMA_PIN, OUTPUT);
  pinMode(AIN1_PIN, OUTPUT);
  pinMode(AIN2_PIN, OUTPUT);

  pinMode(PWMB_PIN, OUTPUT);
  pinMode(BIN1_PIN, OUTPUT);
  pinMode(BIN2_PIN, OUTPUT);
  


  // Terminal virtual Proteus
  // TX = D0(GPIO1)
  // RX = D1(GPIO3)
 
  Serial.begin(9600);


  detener();

  Serial.println("Robot Soccer ESP32 listo");
  Serial.println("Comandos:");
  Serial.println("adelante");
  Serial.println("atras");
  Serial.println("izquierda");
  Serial.println("derecha");
  Serial.println("detener");
  Serial.println("velocidad=0-255");

}



// ---------------- MOVIMIENTOS ----------------


// Adelante
void moverAdelante() {

  // Motor izquierdo
  digitalWrite(AIN1_PIN, LOW);
  digitalWrite(AIN2_PIN, HIGH);


  // Motor derecho
  digitalWrite(BIN1_PIN, HIGH);
  digitalWrite(BIN2_PIN, LOW);


  analogWrite(PWMA_PIN, VELOCIDAD);
  analogWrite(PWMB_PIN, VELOCIDAD);

}



// Atrás
void moverAtras() {


  digitalWrite(AIN1_PIN, HIGH);
  digitalWrite(AIN2_PIN, LOW);


  digitalWrite(BIN1_PIN, LOW);
  digitalWrite(BIN2_PIN, HIGH);


  analogWrite(PWMA_PIN, VELOCIDAD);
  analogWrite(PWMB_PIN, VELOCIDAD);

}



// Giro izquierda
void girarIzquierda() {


  // Motor izquierdo atrás
  digitalWrite(AIN1_PIN, HIGH);
  digitalWrite(AIN2_PIN, LOW);


  // Motor derecho adelante
  digitalWrite(BIN1_PIN, HIGH);
  digitalWrite(BIN2_PIN, LOW);


  analogWrite(PWMA_PIN, VELOCIDAD);
  analogWrite(PWMB_PIN, VELOCIDAD);

}



// Giro derecha
void girarDerecha() {


  // Motor izquierdo adelante
  digitalWrite(AIN1_PIN, LOW);
  digitalWrite(AIN2_PIN, HIGH);


  // Motor derecho atrás
  digitalWrite(BIN1_PIN, LOW);
  digitalWrite(BIN2_PIN, HIGH);


  analogWrite(PWMA_PIN, VELOCIDAD);
  analogWrite(PWMB_PIN, VELOCIDAD);

}



// Detener
void detener() {

  analogWrite(PWMA_PIN,0);
  analogWrite(PWMB_PIN,0);

}



// ---------------- CONTROL SERIAL ----------------


void recibirComando(){


  if(Serial.available()){


    String comando = Serial.readStringUntil('\n');


    comando.trim();


    comando.toLowerCase();



    // Movimiento

    if(comando=="adelante"){

      moverAdelante();
      Serial.println("Movimiento: Adelante");

    }


    else if(comando=="atras"){

      moverAtras();
      Serial.println("Movimiento: Atras");

    }


    else if(comando=="izquierda"){

      girarIzquierda();
      Serial.println("Movimiento: Izquierda");

    }


    else if(comando=="derecha"){

      girarDerecha();
      Serial.println("Movimiento: Derecha");

    }


    else if(comando=="detener"){

      detener();
      Serial.println("Motores detenidos");

    }



    // Control velocidad

    else if(comando.startsWith("velocidad=")){


      String valor = comando.substring(10);


      int nuevaVelocidad = valor.toInt();



      if(nuevaVelocidad >=0 && nuevaVelocidad<=255){


        VELOCIDAD=nuevaVelocidad;


        Serial.print("Velocidad PWM = ");
        Serial.println(VELOCIDAD);

      }

      else{

        Serial.println("Valor fuera de rango 0-255");

      }

    }


    else{

      Serial.println("Comando no reconocido");

    }

  }

}




// ---------------- LOOP ----------------


void loop(){


  recibirComando();


}

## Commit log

2026-08-07 se agrego el archivo .gitignore
2026-08-07 se esta agregando los archivos de del directorio (PITBULL-V2.0.0) con ruta absoluta /home/tronyx/PITBULL-V2.0.0 al control de versiones de git
    [SOCCER_CORREGIDO_3D.f3d]
2026-08-07 se modifico el nombre del archivo README01.md a README.md
2026-08-07 se agrego elimino el archivo git el cual fue creado por error
2026-08-07 se elimino el archivo obsoleto README_V.0.0
2026-08-07 se agrego mejoras en la documentacion
2026-08-07 se renombro las imagenes: diagrama general soccer.png --> diagrama_general_soccer.png y equivalencia de pines.png --> equivalencia_de_pines.png
2026-08-07 mejoras en la documentacion
2026-10-01 se modifico, el pin 35 y se le reemplazo por el 7 puesto que el 35 sequemo (no es un pin adecuado para PWM). Tambien se modico los difercias les porque la izquierda y la derecha estaban invertidos (i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
